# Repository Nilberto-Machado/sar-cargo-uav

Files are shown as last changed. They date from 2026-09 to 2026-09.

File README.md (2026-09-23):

# SAR Cargo UAV

## Overview

**SAR Cargo UAV** is an engineering project focused on the development of a long-range unmanned aerial vehicle for **Search and Rescue (SAR)**, emergency logistics, and transport of critical payloads to remote or difficult-to-access locations.

The project explores a **fixed-wing / hybrid VTOL UAV architecture** designed to combine efficient long-range cruise performance with the operational flexibility of vertical takeoff and landing.

The current design target is a UAV capable of transporting approximately **5 kg of useful payload** over missions of up to approximately **400 km**, with emphasis on endurance, manufacturability, aerodynamic efficiency, operational safety, and field deployment.

---

## Mission

The UAV is intended to support operations such as:

- Search and rescue missions
- Emergency medical supply delivery
- Transport of medicines, blood bags, and medical equipment
- Delivery of food, water, radios, batteries, and survival equipment
- Support to isolated communities
- Disaster response
- Logistics in areas affected by floods, landslides, fires, or infrastructure failure
- Long-range autonomous cargo missions
- Support to remote industrial and mining operations

---

## Main Design Targets

| Parameter | Target |
|---|---:|
| Payload | ~5 kg |
| Mission range | Up to ~400 km |
| Aircraft type | Fixed-wing / Hybrid VTOL UAV |
| Propulsion | Gasoline-based cruise propulsion under evaluation |
| Takeoff / landing | Conventional and/or VTOL architecture |
| Navigation | Autonomous / GPS-assisted |
| Mission type | Cargo, SAR and emergency logistics |
| Design approach | Modular and manufacturable |

These values represent current engineering targets and may evolve during aerodynamic, structural, propulsion, and operational studies.

---

## Aircraft Architecture

Several configurations are being evaluated as part of the project.

Current concepts include:

- Fixed-wing cargo UAV
- Hybrid VTOL
- Tilt-rotor configurations
- V-tail configurations
- Safe transition between hover and forward flight
- Modular propulsion arrangements
- Manufacturable fuselage concepts

The objective is to identify the best compromise between:

- range;
- payload;
- endurance;
- aerodynamic efficiency;
- structural mass;
- propulsion efficiency;
- VTOL capability;
- reliability;
- manufacturing complexity;
- maintenance;
- operational safety.

---

## Engineering Workflow

The project uses an iterative engineering workflow combining CAD, simulation, scripting, and design reviews.

```text
Mission Requirements
        │
        ▼
Conceptual Design
        │
        ▼
Aircraft Geometry
        │
        ▼
FreeCAD Parametric Model
        │
        ├──► Structural / Packaging Assessment
        │
        ├──► Propulsion Integration
        │
        └──► Transition / Collision Analysis
        │
        ▼
CFD Geometry Export
        │
        ▼
OpenFOAM
        │
        ▼
Aerodynamic Analysis
        │
        ▼
Design Optimization
        │
        ▼
Manufacturable Configuration
```

---

## CAD

The aircraft geometry is being developed primarily using **FreeCAD**.

The repository includes scripts and macros used to generate and evaluate multiple aircraft configurations.

Areas currently under development include:

- fuselage geometry;
- wing geometry;
- V-tail;
- propulsion mounting;
- cargo compartment;
- VTOL propulsion;
- tilt mechanisms;
- component clearance;
- aircraft packaging;
- manufacturability.

Python automation is used extensively to generate and evaluate alternative geometries.

---

## CFD

Aerodynamic simulation is performed using **OpenFOAM**.

The CFD workflow is intended to evaluate:

- external aerodynamic flow;
- pressure distribution;
- lift;
- drag;
- aerodynamic efficiency;
- wake structures;
- propulsion-airframe interaction;
- aerodynamic effects of VTOL components;
- stability-related characteristics.

Typical workflow:

```text
FreeCAD
   │
   ▼
Geometry Export
   │
   ▼
STL / CFD Geometry
   │
   ▼
OpenFOAM Mesh
   │
   ▼
Flow Simulation
   │
   ▼
Aerodynamic Results
```

---

## VTOL Development

Hybrid VTOL configurations are being investigated to enable operations where conventional runways are unavailable.

Engineering studies include:

- rotor placement;
- tilt mechanisms;
- transition between hover and cruise;
- mechanical interference;
- propeller clearance;
- center-of-gravity effects;
- propulsion redundancy;
- safe transition trajectories.

Several scripts in the repository are dedicated to collision detection and transition studies.

Examples include:

```text
check_tilt_collisions.py
check_mirrored_tilt_collisions.py
sweep_rear_tilt_pivot.py
```

---

## Manufacturability

A major objective of the project is to evolve from conceptual aircraft geometry toward a configuration that can realistically be manufactured.

Design considerations include:

- composite structures;
- aluminum components;
- modular construction;
- removable wings;
- propulsion accessibility;
- maintenance access;
- cargo loading;
- landing gear;
- component standardization;
- assembly sequence;
- field repairability.

---

## Repository Structure

The repository currently contains engineering tools, models, documentation, and simulation environments.

Example structure:

```text
sar-cargo-uav/
│
├── openfoam/
│   └── CFD simulation cases
│
├── Tech Spec/
│   └── Technical specifications
│
├── uav_cargo_freecad/
│   └── FreeCAD models
│
├── uav_cargo_vtol/
│   └── VTOL configurations
│
├── uav_cargo_refined/
│   └── Refined aircraft geometry
│
├── uav_cargo_manufacturable/
│   └── Manufacturable configuration
│
├── uav_cargo_animation/
│   └── Aircraft animations
│
├── uav_cargo_safe_transition/
│   └── VTOL transition studies
│
├── assess_fuselage_layout.py
├── build_uav_vtol_headless.py
├── check_tilt_collisions.py
├── check_mirrored_tilt_collisions.py
├── export_manufacturable_cfd.py
├── sweep_rear_tilt_pivot.py
│
└── README.md
```

The directory structure may change as the project evolves.

---

## Main Tools

The engineering workflow currently uses:

- **FreeCAD** — parametric aircraft modeling
- **Python** — geometry generation and engineering automation
- **OpenFOAM** — computational fluid dynamics
- **Git / GitHub** — version control
- **PowerShell** — development environment automation
- **ParaView** — CFD visualization

---

## Design Priorities

The development follows several key priorities.

### 1. Mission capability

The UAV must be capable of transporting a meaningful payload over long distances.

### 2. Aerodynamic efficiency

Long-range missions require high lift-to-drag efficiency and careful aerodynamic optimization.

### 3. Operational flexibility

VTOL capability may allow operations without conventional runways.

### 4. Reliability

Search-and-rescue aircraft must prioritize predictable and fault-tolerant behavior.

### 5. Manufacturability

The design should be capable of progressing from a CAD concept to an aircraft that can realistically be manufactured and maintained.

### 6. Modular architecture

Subsystems should be replaceable and configurable whenever practical.

---

## Future Development

Planned engineering activities include:

- aerodynamic optimization;
- wing sizing refinement;
- propulsion sizing;
- gasoline engine evaluation;
- propeller optimization;
- VTOL propulsion sizing;
- fuel consumption modeling;
- center-of-gravity analysis;
- stability analysis;
- structural analysis;
- landing gear design;
- cargo compartment refinement;
- flight-control architecture;
- autopilot integration;
- telemetry;
- communication systems;
- mission planning;
- redundancy analysis;
- fail-safe architecture;
- prototype manufacturing;
- ground testing;
- flight testing.

---

## Project Philosophy

SAR Cargo UAV is being developed as an engineering platform rather than only as a single aircraft model.

The long-term objective is to build a modular design and simulation environment capable of supporting multiple UAV configurations for emergency logistics and autonomous cargo transportation.

The project combines:

**CAD + CFD + automation + simulation + manufacturing engineering + autonomous flight systems**

into a unified development workflow.

---

## Project Status

**Current phase:** Concept development / preliminary engineering.

The aircraft geometry,

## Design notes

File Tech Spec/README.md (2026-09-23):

# Tech Spec — UAV híbrido VTOL cargueiro/de resgate

Pacote consolidado em 22/09/2026.

## Conteúdo

- `Tech_Spec_UAV_Hybrid_VTOL.docx`: documento mestre para revisão.
- `TECH_SPEC.md`: especificação técnica controlada em texto.
- `BOM_Compras.csv`: lista mestra de compras.
- `Data sheets/`: uma ficha técnica para cada uma das 71 linhas da BOM.

## Regra de maturidade

Nenhum item marcado **compra bloqueada**, **TBD crítico**, **TBD** ou **sob medida** está liberado para pedido. “Arquitetura aceita” significa que a função foi aceita, não que a integração esteja certificada.

## Próximos gates

1. Fechar orçamento de massa, MTOW e centro de gravidade.
2. Medir empuxo/corrente/temperatura do conjunto VTOL.
3. Medir empuxo e consumo do motor a gasolina com hélice pusher.
4. Dimensionar pivôs, atuadores, travas e sensores de indexação.
5. Fechar balanço de energia e pack 12S.
6. Executar análise estrutural e prova de carga.
7. Atualizar CFD com camadas de parede e efeitos propulsivos.

O arquivo FreeCAD de referência permanece em `../uav_cargo_manufacturable/CargoUAV_HybridVTOL_Manufacturable.FCStd`.

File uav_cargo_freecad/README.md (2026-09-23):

# UAV cargueiro paramétrico — FreeCAD / OpenFOAM

Modelo conceitual simplificado de uma aeronave cargueira não tripulada, de asa fixa,
para CFD externo. A geometria evita antenas, dobradiças, entradas de ar, parafusos e
outras escalas pequenas que encarecem o `snappyHexMesh` sem ajudar na análise global.

> Este é um modelo aerodinâmico conceitual, não um projeto estrutural, de estabilidade,
> propulsão ou certificação. As metas de 5 kg e 400 km são requisitos de missão ainda
> não demonstrados por este CAD.

## Arquivos

- `CargoUAV_CFD.FCStd` — documento nativo FreeCAD com parâmetros, sólido principal e
  disco atuador opcional.
- `build_uav.py` — fonte paramétrica; altere `PARAMS` e execute novamente para regenerar.
- `exports/CargoUAV_airframe.step` — aerofólio/fuselagem/empenagem unidos em um sólido.
- `exports/CargoUAV_with_propeller_disk.step` — sólido principal mais o disco opcional.
- `exports/CargoUAV_airframe.stl` — superfície triangulada principal para OpenFOAM.
- `exports/CargoUAV_propeller_disk.stl` — disco separado para modelo atuador/MRF.
- `validation_report.txt` — verificação de validade, fechamento, sólidos e dimensões.

## Dimensões principais

| Parâmetro | Valor |
|---|---:|
| Comprimento da fuselagem | 2,850 m |
| Envergadura | 4,200 m |
| Corda da asa, raiz / ponta | 0,620 / 0,340 m |
| Perfil da asa | NACA 0012 simétrico simplificado |
| Envergadura do estabilizador horizontal | 1,350 m |
| Altura da deriva | 0,620 m |
| Diâmetro do disco da hélice pusher | 0,900 m |
| Largura / altura máximas da fuselagem | 0,520 / 0,600 m |
| Meta de carga útil | 5 kg |
| Meta de alcance | 400 km |

Sistema de eixos: `+X` para a cauda, `+Y` para a asa direita e `+Z` para cima. O CAD e
os STEP/STL estão em milímetros.

## Parametrização e nova exportação

1. Edite somente o dicionário `PARAMS` no início de `build_uav.py`.
2. Execute no Prompt/PowerShell:

   ```powershell
   & "E:\Program Files\FreeCAD 1.1\bin\FreeCADCmd.exe" build_uav.py
   ```

3. Abra `CargoUAV_CFD.FCStd` para inspeção visual. O objeto `Parameters` registra os
   valores usados; a fonte de verdade para regeneração é `build_uav.py`.

No FreeCAD GUI, uma exportação manual equivalente é: selecione `Airframe`, use
**File > Export**, escolha STEP ou STL e mantenha milímetros. Para o STL fornecido, a
deflexão linear usada é 1,0 mm e a angular é 0,15 rad.

## Uso no OpenFOAM / snappyHexMesh

1. Copie `CargoUAV_airframe.stl` para `constant/triSurface/`.
2. Como o OpenFOAM normalmente trabalha em metros, aplique escala `0.001` ao importar
   (por exemplo, com `surfaceTransformPoints -scale '(0.001 0.001 0.001)'`). Confirme a
   sintaxe exata da sua versão do OpenFOAM.
3. Rode `surfaceCheck constant/triSurface/CargoUAV_airframe.stl`. O resultado esperado
   é uma superfície fechada, sem bordas abertas e com uma região principal.
4. No `snappyHexMeshDict`, use o STL como `triSurfaceMesh`, marque a superfície como
   `wall` e posicione `locationInMesh` no domínio externo, longe da aeronave.
5. Comece com 2–3 níveis de refinamento na aeronave, adicione caixas de refinamento na
   esteira e faça estudo de independência de malha. Refine bordo de ataque, bordo de
   fuga e ponta de asa conforme o objetivo aerodinâmico.
6. Para uma primeira simulação de célula limpa, ignore o arquivo do disco. Para empuxo
   simplificado, importe o disco separadamente e configure-o segundo o modelo atuador,
   `fvOptions` ou região rotativa compatível com sua versão do OpenFOAM.

O sólido principal foi unido por Boolean e salvo como um único corpo fechado. O disco
da hélice é deliberadamente separado porque não faz parte da parede estanque do avião.

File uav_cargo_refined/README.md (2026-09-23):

# UAV cargueiro híbrido VTOL - revisão aerodinâmica fundamentada

Esta pasta contém uma nova variante paramétrica. Ela preserva os modelos anteriores e
aplica critérios de projeto conceitual, aerodinâmica de asa e estabilidade extraídos das
referências técnicas fornecidas pelo usuário.

## Alterações principais

- asa de 4,20 m mantida, com área reduzida de 2,604 para 2,268 m²;
- alongamento aumentado de 6,77 para 7,78;
- taper alterado de 0,512 para 0,459, próximo ao valor recomendado para asa reta;
- perfil simétrico substituído por NACA 2415 na raiz, transicionando para NACA 2412;
- incidência de +2° na raiz e 0° na ponta, criando 2° de washout;
- cauda em V aumentada e inclinada a 38°, com volumes equivalentes aproximados
  `Vh = 0,50` e `Vv = 0,041`;
- CG preliminar consolidado em X=1,070 m, com envelope X=1,010-1,120 m;
- naceles de cruzeiro suavizadas e hélice pusher aumentada de 0,54 para 0,60 m;
- fuselagem preserva o volume central, mas recebe nariz e cone de cauda mais suaves.

## Arquivos gerados

- `CargoUAV_Refined_CFD.FCStd`: modelo nativo FreeCAD;
- `exports/CargoUAV_Refined_airframe.step`: sólido externo watertight;
- `exports/CargoUAV_Refined_airframe.stl`: superfície para `snappyHexMesh`;
- `exports/CargoUAV_Refined_with_pusher.step`: fuselagem e disco pusher separado;
- `exports/CargoUAV_Refined_complete.step`: airframe e cinco discos separados;
- `validation_report.json`: validade geométrica e métricas calculadas.

## Regeneração

```powershell
& "E:\Program Files\FreeCAD 1.1\bin\FreeCADCmd.exe" build_refined_uav.py
```

## Estado de maturidade

Este é um candidato conceitual, não um projeto liberado para fabricação. A alteração de
asa invalida a malha CFD anterior. Antes de congelar a geometria, são obrigatórios:

1. nova malha OpenFOAM com camadas prismáticas e estudo de independência;
2. polar incluindo transição/estol e avaliação de `y+`;
3. VLM ou CFD para ponto neutro, margem estática e autoridade dos ruddervators;
4. fechamento real de massa/CG em todas as condições de combustível e carga;
5. dimensionamento estrutural, aeroelasticidade, flutter e ensaios dos tilt-rotors.

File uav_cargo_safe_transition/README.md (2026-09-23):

# Transição segura dos motores basculantes

Esta macro substitui a sequência anterior, que inclinava os motores enquanto as hélices
ainda giravam. O novo intertravamento impede qualquer movimento de tilt enquanto a RPM
dos rotores elétricos for diferente de zero ou a trava das pás não estiver confirmada.

## Sequência

| Tempo | Operação | VTOL | Tilt | Pusher |
|---:|---|---:|---:|---:|
| 0–6 s | Spin-up e decolagem | até 1600 rpm | 0° | parada |
| 6–9 s | Partida da pusher | 1600 rpm | 0° | 0→5200 rpm |
| 9–11 s | Transferência de sustentação | 1600→0 rpm | 0° | 5200→6200 rpm |
| 11–12 s | Indexação transversal das pás | 0 rpm | 0° | 6200 rpm |
| 12–14 s | Basculamento após travamento | 0 rpm e travado | 0→−90° | 6200→6500 rpm |
| 14–20 s | Cruzeiro | parado e travado | −90° | 6500 rpm |

As pás são estacionadas a 90° no eixo local, ficando transversais ao boom antes do
basculamento. O estado pode ser acompanhado nas propriedades `RotorLock` e
`TiltPermission` de `AnimationState`.

Este intertravamento é apenas lógico/cinemático. Um mecanismo real também deve possuir
sensor de RPM zero, encoder de posição, pino de trava redundante, detecção de trava,
limites mecânicos e procedimento de retorno caso alguma unidade não confirme a posição.

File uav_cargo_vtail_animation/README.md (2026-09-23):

# Animação corrigida com cauda em V e motores basculantes

Esta revisão substitui a empenagem convencional por duas superfícies inclinadas a 40°
e adiciona basculamento aos quatro conjuntos elétricos.

Cada conjunto possui duas juntas independentes:

- `Joint_Tilt_*`: revolução em torno do eixo transversal local `+Y`, com curso de 0°
  na decolagem a −90° no cruzeiro.
- `Joint_Spin_*`: rotação da hélice em torno de `+Z` local ao pod. Como é filha do
  conjunto basculante, a direção desse eixo acompanha a inclinação do motor.

| Motor | Pivô de basculamento em mm | Eixo de tilt | Centro do rotor relativo ao pivô |
|---|---:|---:|---:|
| FL | `(600, -950, 53,4)` | `(0, 1, 0)` | `(0, 0, 167)` |
| FR | `(600, 950, 53,4)` | `(0, 1, 0)` | `(0, 0, 167)` |
| RL | `(1850, -950, 53,4)` | `(0, 1, 0)` | `(0, 0, 167)` |
| RR | `(1850, 950, 53,4)` | `(0, 1, 0)` | `(0, 0, 167)` |

Durante a transição, a hélice traseira acelera de 0 a 6000 rpm enquanto os pods passam
de 0° para −90° e os rotores elétricos reduzem de 1600 rpm até parar. No cruzeiro, os
discos elétricos ficam alinhados com o escoamento para reduzir a área frontal.

Para executar, abra `CargoUAV_HybridVTOL_VTail_TiltRotor_Animated.FCStd` e rode
`RunVTailTiltRotorAnimation.FCMacro` em **Macro > Macros**. Use a macro `Stop...` para
parar e retornar à posição inicial.

Esta é uma verificação cinemática. O mecanismo real ainda necessita dimensionamento de
atuador, rolamentos, trava mecânica, velocidade de basculamento e análise de cargas.

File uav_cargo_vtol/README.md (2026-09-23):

# UAV cargueiro híbrido VTOL — FreeCAD e OpenFOAM

Revisão do modelo conceitual para a configuração consolidada: quatro motores elétricos
de sustentação vertical, motor traseiro a gasolina para cruzeiro e starter-generator.
O corpo principal continua simplificado e adequado a CFD externo.

## Configuração representada

| Parâmetro | Valor |
|---|---:|
| Envergadura | 4,20 m |
| Comprimento | 2,85 m |
| Área alar geométrica | 2,604 m² |
| Alongamento | 6,77 |
| Corda da asa, raiz / ponta | 0,82 / 0,42 m |
| Rotores VTOL | 4 × 0,76 m |
| Hélice pusher representada | 0,54 m |
| Carga útil alvo | 5 kg |
| MTOW preliminar | 21 kg |
| Bateria VTOL de referência | 12S, 800 Wh |
| Starter-generator de referência | 750 W |
| Tanque preliminar | 4 L |
| Alcance pretendido | 400 km |

O MTOW, potência dos motores, bateria e combustível ainda são parâmetros preliminares.
O CAD não demonstra desempenho, autonomia, resistência estrutural ou segurança de voo.

## Arquivos

- `CargoUAV_HybridVTOL_CFD.FCStd`: documento nativo FreeCAD.
- `build_uav_vtol.py`: fonte paramétrica e regenerável.
- `exports/CargoUAV_HybridVTOL_airframe.step`: sólido externo limpo, sem discos.
- `exports/CargoUAV_HybridVTOL_airframe.stl`: parede externa para `snappyHexMesh`.
- `exports/CargoUAV_HybridVTOL_complete.step`: airframe e cinco discos separados.
- `exports/CargoUAV_HybridVTOL_pusher_disk.stl`: disco do motor a gasolina.
- `exports/CargoUAV_HybridVTOL_vtol_disks.stl`: quatro discos elétricos.
- `validation_report.txt`: validade, fechamento, número de sólidos e dimensões.

O documento FreeCAD também contém envelopes internos ocultos para carga útil, bateria
VTOL, tanque de combustível e starter-generator. Esses objetos não são exportados para
os arquivos de CFD.

## Regeneração

Edite `P` no início de `build_uav_vtol.py` e execute:

```powershell
& "E:\Program Files\FreeCAD 1.1\bin\FreeCADCmd.exe" build_uav_vtol.py
```

Para conferir todos os arquivos depois da geração:

```powershell
& "E:\Program Files\FreeCAD 1.1\bin\FreeCADCmd.exe" validate_delivery.py
```

## Uso no OpenFOAM

Copie `CargoUAV_HybridVTOL_airframe.stl` para `constant/triSurface/`. Os arquivos estão
em milímetros; converta para metros com escala `0.001`. Execute `surfaceCheck` antes do
`snappyHexMesh`. Para CFD de cruzeiro limpo, use apenas o airframe. Importe os discos
separadamente somente em casos com modelo atuador ou região rotativa.

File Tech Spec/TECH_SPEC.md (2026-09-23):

# Especificação técnica consolidada

## Configuração
- **Tipo:** UAV cargueiro/de resgate híbrido VTOL de asa fixa
- **Status:** Configuração conceitual consolidada; não liberada para fabricação ou compra integral
- **Envergadura:** 4,20 m
- **Comprimento:** 2,85 m (envelope atual; requisito inicial 2,6–3,0 m)
- **Área alar:** 2,604 m²
- **Corda raiz / ponta:** 0,820 m / 0,420 m
- **Afilamento:** 0,512
- **Corda aerodinâmica média:** 0,6415 m
- **Alongamento geométrico:** AR ≈ 6,77
- **Empenagem:** Cauda em V, ângulo consolidado de 40°
- **Carga útil:** Até 5 kg — meta
- **Alcance:** 400 km — meta a validar por ensaio de consumo e reserva
- **Velocidade CFD de referência:** 25 m/s, α = 0°
- **Centro de gravidade alvo:** x ≈ 1,05–1,085 m; referência de momentos x = 1,07 m
- **Propulsão VTOL:** 4 motores elétricos 12S em naceles inclináveis
- **Pivôs dianteiros:** x = 0,600 m; inclinação de cruzeiro para frente: −90°
- **Pivôs traseiros:** x = 2,000 m; inclinação de cruzeiro para trás: +90°
- **Propulsão de cruzeiro:** Motor traseiro a gasolina em configuração pusher
- **Geração elétrica:** Starter-generator dedicado; motores VTOL não são assumidos como geradores nesta revisão
- **MTOW:** TBD — gate obrigatório antes da compra de motores, ESCs, pack, tilt, estrutura e paraquedas

## Conceito operacional

A aeronave decola e pousa verticalmente com quatro rotores elétricos. Após atingir altura e condições seguras, o motor traseiro a gasolina é acionado pelo sistema starter-generator e assume o cruzeiro. O starter-generator pode alimentar o barramento e recarregar a bateria dentro dos limites do pack. Os motores VTOL não são considerados geradores nesta revisão, evitando arrasto, controle complexo e riscos de overspeed.

## Intertravamento obrigatório dos tilt-rotors

A nacele só pode iniciar o movimento quando, para aquele rotor, houver confirmação independente de: comando de torque zero; RPM abaixo do limite; hélice na janela angular indexada; trava da posição atual liberada; trajetória livre; e alimentação do atuador válida. Ao chegar à nova posição, a trava mecânica deve engatar e dois sinais coerentes devem confirmar posição/trava antes de liberar potência ao motor.

Sequência de falha: qualquer discordância congela a transição, mantém ou retorna à última posição mecanicamente segura e impede reenergização do rotor afetado. Os rotores dianteiros giram para frente; os traseiros giram para trás. É proibido girar naceles com hélices em rotação livre significativa.

## Estado da validação CFD

Caso base OpenFOAM 14, 25 m/s e α=0°, malha de 269.773 células. Resultado preliminar médio entre passos 140–150: Cd≈0,06546, Cl≈−0,01247 e Cm≈0,01091. A malha ainda não possui camadas de parede nem representação das hélices; os coeficientes não liberam o projeto.

## Gates de liberação de compras

- G1 Massa/CG: MTOW, centros de massa e envelopes fechados.
- G2 VTOL: razão empuxo/peso ≥1,5 e margens elétricas/térmicas medidas.
- G3 Cruzeiro: potência, consumo, alcance de 400 km e reserva demonstrados.
- G4 Tilt: cargas, folgas, indexação, travas e análise de falha aprovadas.
- G5 Energia: pack, proteção, redundância e starter-generator validados.
- G6 Estrutura: cargas limite/última, FEA e provas estáticas concluídas.
- G7 Segurança/operação: paraquedas, failsafes, regulamentação e plano de ensaios aprovados.

## Rastreabilidade e ressalvas

As dimensões acima vêm do modelo paramétrico atual. Cálculos antigos do documento Arduino (como asa de 3 m e massas de 10/19 kg) são históricos e foram superados quando conflitantes. Modelos comerciais listados são candidatos técnicos, não autorização de compra. Confirme revisão, disponibilidade, homologação e ficha oficial diretamente com o fabricante no momento da aquisição.

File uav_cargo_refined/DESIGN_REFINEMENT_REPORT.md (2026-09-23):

# Relatório de refinamento aerodinâmico

## Base de decisão

A revisão usa os princípios convergentes das referências fornecidas: arrasto induzido
decresce com o alongamento; taper próximo de 0,4-0,5 é apropriado para asas retas;
washout favorece estol iniciando na raiz; Reynolds e rugosidade devem ser compatíveis
com os dados de perfil; e a cauda deve ser dimensionada por volume e verificada por
margem estática e dinâmica.

## Comparação geométrica

| Parâmetro | Modelo anterior | Revisão |
|---|---:|---:|
| Envergadura | 4,20 m | 4,20 m |
| Área alar | 2,604 m² | 2,268 m² |
| Alongamento | 6,77 | 7,78 |
| Taper | 0,512 | 0,459 |
| Perfil | NACA 00xx simétrico | NACA 2415 -> 2412 |
| Twist geométrico | 0° | 2° de washout |
| Área verdadeira da cauda em V | 0,640 m² | 0,770 m² |
| Ângulo da cauda em V | 40° | 38° |
| Volume horizontal equivalente | ~0,29 | ~0,50 |
| Volume vertical equivalente | ~0,031 | ~0,041 |
| Referência de CG | conflitante: 1,07/1,35 m | alvo 1,070 m |

## Desempenho preliminar calculado

Com MTOW ainda preliminar de 21 kg e velocidade de cruzeiro de 21 m/s:

- carga alar: aproximadamente 90,8 N/m² (9,26 kg/m²);
- `Cl` de cruzeiro requerido: aproximadamente 0,337;
- velocidade de estol estimada: 10,7 m/s para `Clmax=1,3`;
- Reynolds de cruzeiro: aproximadamente 1,04 milhão na raiz e 0,48 milhão na ponta;
- área total dos quatro discos VTOL: aproximadamente 1,815 m².

Esses números são verificações de coerência, não garantias de desempenho.

## Relação com o CFD existente

A polar anterior mostrou crescimento de sustentação até +12°, aumento rápido de
arrasto acima de +8° e momento de arfagem progressivamente negativo. Ela continua útil
como referência do desenho anterior, mas não pode ser transferida para a nova asa. O
perfil cambrado, o washout, a área menor e a cauda maior exigem remalhamento completo.

## Gates antes de fabricação

- pesar todos os componentes e fechar MTOW/CG, incluindo combustível consumido;
- demonstrar margem estática positiva no envelope inteiro, com meta inicial de 10-18%;
- verificar controle em pitch/yaw e acoplamento adverso da cauda em V em 6-DOF;
- verificar que o estol começa na raiz e preserva autoridade dos ailerons;
- validar potência, hélices e transição VTOL em bancada e em testes progressivos;
- executar análise estrutural, cargas de rajada, fadiga e flutter.

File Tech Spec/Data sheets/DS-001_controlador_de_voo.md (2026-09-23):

# DS-001 — Controlador de voo

## Identificação

| Campo | Valor |
|---|---|
| Categoria | Aviónica |
| Quantidade | 1 |
| Maturidade | Arquitetura aceita |
| Candidato/modelo | Holybro Pixhawk 6X |
| Liberação de compra | Revisão de integração obrigatória antes do pedido |

## Função

Controle de voo, navegação, failsafes e registro primário.

## Requisitos mínimos de compra

Autopiloto classe H7, IMUs redundantes, barômetros redundantes, CAN, Ethernet e entradas de alimentação redundantes.

## Interfaces

MAVLink/CAN/UART; 5 V regulados; servo rail isolado.

## Critérios de aceitação

Teste de alimentação A/B, sensores, logging, watchdog, RTL e perda de enlace.

## Dependências antes da seleção

Firmware ArduPilot/PX4 e integração do sistema de energia.

## Data sheet de referência

https://docs.holybro.com/autopilot/pixhawk-6x/technical-specification

## Documentos que o fornecedor deve entregar

- Data sheet com revisão e part number exatos.
- Desenho dimensional e interfaces.
- Limites elétricos, térmicos, mecânicos e ambientais aplicáveis.
- Curvas de desempenho relevantes e condições do ensaio.
- Certificado de material/conformidade quando aplicável.
- Instruções de instalação, inspeção e vida útil/manutenção.

## Registro de recebimento

- Fabricante / fornecedor: ____________________
- Part number / revisão: ____________________
- Lote / número de série: ____________________
- Data de recebimento: ____________________
- Inspeção de recebimento: APROVADO / REPROVADO
- Responsável: ____________________

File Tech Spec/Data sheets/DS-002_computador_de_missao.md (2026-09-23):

# DS-002 — Computador de missão

## Identificação

| Campo | Valor |
|---|---|
| Categoria | Aviónica |
| Quantidade | 1 |
| Maturidade | Arquitetura aceita |
| Candidato/modelo | Raspberry Pi 5 — 8 GB |
| Liberação de compra | Revisão de integração obrigatória antes do pedido |

## Função

Visão computacional, comunicações de alto nível e processamento de missão.

## Requisitos mínimos de compra

BCM2712, 8 GB, alimentação 5 V/5 A, refrigeração ativa e desligamento controlado.

## Interfaces

Ethernet/USB/UART com Pixhawk; câmera CSI; armazenamento local.

## Critérios de aceitação

Burn-in de 4 h, carga de CPU, perda/retorno de energia e temperatura no compartimento.

## Dependências antes da seleção

Conversores DC/DC redundantes e solução térmica.

## Data sheet de referência

https://datasheets.raspberrypi.com/rpi5/raspberry-pi-5-product-brief.pdf

## Documentos que o fornecedor deve entregar

- Data sheet com revisão e part number exatos.
- Desenho dimensional e interfaces.
- Limites elétricos, térmicos, mecânicos e ambientais aplicáveis.
- Curvas de desempenho relevantes e condições do ensaio.
- Certificado de material/conformidade quando aplicável.
- Instruções de instalação, inspeção e vida útil/manutenção.

## Registro de recebimento

- Fabricante / fornecedor: ____________________
- Part number / revisão: ____________________
- Lote / número de série: ____________________
- Data de recebimento: ____________________
- Inspeção de recebimento: APROVADO / REPROVADO
- Responsável: ____________________

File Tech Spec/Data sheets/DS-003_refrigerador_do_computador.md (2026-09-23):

# DS-003 — Refrigerador do computador

## Identificação

| Campo | Valor |
|---|---|
| Categoria | Aviónica |
| Quantidade | 1 |
| Maturidade | Candidato |
| Candidato/modelo | Raspberry Pi Active Cooler |
| Liberação de compra | BLOQUEADA até fechamento dos gates aplicáveis |

## Função

Manter o computador de missão abaixo do limite térmico.

## Requisitos mínimos de compra

Compatível com Raspberry Pi 5; operação contínua na temperatura interna prevista.

## Interfaces

Conector de fan do Raspberry Pi 5; fluxo de ar desobstruído.

## Critérios de aceitação

Teste térmico em solo com CPU a 100% e fuselagem fechada.

## Dependências antes da seleção

Projeto de dutos/ventilação.

## Data sheet de referência

https://www.raspberrypi.com/products/active-cooler/

## Documentos que o fornecedor deve entregar

- Data sheet com revisão e part number exatos.
- Desenho dimensional e interfaces.
- Limites elétricos, térmicos, mecânicos e ambientais aplicáveis.
- Curvas de desempenho relevantes e condições do ensaio.
- Certificado de material/conformidade quando aplicável.
- Instruções de instalação, inspeção e vida útil/manutenção.

## Registro de recebimento

- Fabricante / fornecedor: ____________________
- Part number / revisão: ____________________
- Lote / número de série: ____________________
- Data de recebimento: ____________________
- Inspeção de recebimento: APROVADO / REPROVADO
- Responsável: ____________________

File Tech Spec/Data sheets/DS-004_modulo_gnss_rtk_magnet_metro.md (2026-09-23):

# DS-004 — Módulo GNSS/RTK + magnetômetro

## Identificação

| Campo | Valor |
|---|---|
| Categoria | Aviónica |
| Quantidade | 1 |
| Maturidade | Candidato |
| Candidato/modelo | Holybro H-RTK NEO-F9P + RM3100 |
| Liberação de compra | BLOQUEADA até fechamento dos gates aplicáveis |

## Função

Posição, velocidade, rumo e possibilidade de RTK.

## Requisitos mínimos de compra

Dupla banda GNSS, RTK, magnetômetro RM3100; 4,75–5,25 V; massa aproximada 39 g.

## Interfaces

CAN/UART conforme variante; montagem afastada de potência e ignição.

## Critérios de aceitação

Aquisição a céu aberto, comparação de rumo, interferência com motor a gasolina ligado.

## Dependências antes da seleção

Mastro e plano de aterramento eletromagnético.

## Data sheet de referência

https://docs.holybro.com/gps-and-rtk-system/h-rtk-neo-f9p-series-rm3100-compass/specification

## Documentos que o fornecedor deve entregar

- Data sheet com revisão e part number exatos.
- Desenho dimensional e interfaces.
- Limites elétricos, térmicos, mecânicos e ambientais aplicáveis.
- Curvas de desempenho relevantes e condições do ensaio.
- Certificado de material/conformidade quando aplicável.
- Instruções de instalação, inspeção e vida útil/manutenção.

## Registro de recebimento

- Fabricante / fornecedor: ____________________
- Part number / revisão: ____________________
- Lote / número de série: ____________________
- Data de recebimento: ____________________
- Inspeção de recebimento: APROVADO / REPROVADO
- Responsável: ____________________

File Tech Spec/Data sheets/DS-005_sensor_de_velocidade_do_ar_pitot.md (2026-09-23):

# DS-005 — Sensor de velocidade do ar + pitot

## Identificação

| Campo | Valor |
|---|---|
| Categoria | Aviónica |
| Quantidade | 1 |
| Maturidade | Candidato |
| Candidato/modelo | Holybro MS5525 |
| Liberação de compra | BLOQUEADA até fechamento dos gates aplicáveis |

## Função

Medição de velocidade indicada e proteção do envelope.

## Requisitos mínimos de compra

Sensor diferencial digital, faixa adequada ao voo de 15–40 m/s, tubos resistentes a combustível/calor.

## Interfaces

I²C/CAN via interface; tomadas de pressão total/estática.

## Critérios de aceitação

Calibração zero, teste de vazamento, comparação em túnel/veículo.

## Dependências antes da seleção

Posição do pitot fora da esteira das hélices.

## Data sheet de referência

https://docs.holybro.com/peripherals/ms4525do-and-ms5525dso-i2c-airspeed-sensor

## Documentos que o fornecedor deve entregar

- Data sheet com revisão e part number exatos.
- Desenho dimensional e interfaces.
- Limites elétricos, térmicos, mecânicos e ambientais aplicáveis.
- Curvas de desempenho relevantes e condições do ensaio.
- Certificado de material/conformidade quando aplicável.
- Instruções de instalação, inspeção e vida útil/manutenção.

## Registro de recebimento

- Fabricante / fornecedor: ____________________
- Part number / revisão: ____________________
- Lote / número de série: ____________________
- Data de recebimento: ____________________
- Inspeção de recebimento: APROVADO / REPROVADO
- Responsável: ____________________

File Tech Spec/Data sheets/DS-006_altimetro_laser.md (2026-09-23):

# DS-006 — Altímetro laser

## Identificação

| Campo | Valor |
|---|---|
| Categoria | Aviónica |
| Quantidade | 1 |
| Maturidade | Candidato |
| Candidato/modelo | LightWare SF11/C |
| Liberação de compra | BLOQUEADA até fechamento dos gates aplicáveis |

## Função

Altura precisa na decolagem e no pouso VTOL.

## Requisitos mínimos de compra

Faixa 0,2–100 m, 20 Hz, precisão aproximada ±0,1 m, 5 V, massa aproximada 35 g.

## Interfaces

Serial/I²C; campo de visão desobstruído para baixo.

## Critérios de aceitação

Teste em superfícies clara/escura, poeira e inclinação; comparação com referência.

## Dependências antes da seleção

Janela óptica e suporte antivibração.

## Data sheet de referência

https://lightwarelidar.com/wp-content/uploads/2025/07/SF11-Laser-Altimeter-Manual-Rev-10.pdf

## Documentos que o fornecedor deve entregar

- Data sheet com revisão e part number exatos.
- Desenho dimensional e interfaces.
- Limites elétricos, térmicos, mecânicos e ambientais aplicáveis.
- Curvas de desempenho relevantes e condições do ensaio.
- Certificado de material/conformidade quando aplicável.
- Instruções de instalação, inspeção e vida útil/manutenção.

## Registro de recebimento

- Fabricante / fornecedor: ____________________
- Part number / revisão: ____________________
- Lote / número de série: ____________________
- Data de recebimento: ____________________
- Inspeção de recebimento: APROVADO / REPROVADO
- Responsável: ____________________

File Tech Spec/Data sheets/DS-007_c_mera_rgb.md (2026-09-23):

# DS-007 — Câmera RGB

## Identificação

| Campo | Valor |
|---|---|
| Categoria | Missão |
| Quantidade | 1 |
| Maturidade | Candidato |
| Candidato/modelo | Raspberry Pi Camera Module 3 Wide |
| Liberação de compra | BLOQUEADA até fechamento dos gates aplicáveis |

## Função

Busca visual, registro e apoio à navegação.

## Requisitos mínimos de compra

Sony IMX708, 12 MP, autofoco, variante wide; proteção óptica substituível.

## Interfaces

CSI para Raspberry Pi 5.

## Critérios de aceitação

Foco, exposição, vibração, rolling shutter e gravação sustentada.

## Dependências antes da seleção

Cabo CSI com comprimento final e janela frontal.

## Data sheet de referência

https://datasheets.raspberrypi.com/camera/camera-module-3-product-brief.pdf

## Documentos que o fornecedor deve entregar

- Data sheet com revisão e part number exatos.
- Desenho dimensional e interfaces.
- Limites elétricos, térmicos, mecânicos e ambientais aplicáveis.
- Curvas de desempenho relevantes e condições do ensaio.
- Certificado de material/conformidade quando aplicável.
- Instruções de instalação, inspeção e vida útil/manutenção.

## Registro de recebimento

- Fabricante / fornecedor: ____________________
- Part number / revisão: ____________________
- Lote / número de série: ____________________
- Data de recebimento: ____________________
- Inspeção de recebimento: APROVADO / REPROVADO
- Responsável: ____________________

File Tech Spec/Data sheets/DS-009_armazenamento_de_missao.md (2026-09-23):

# DS-009 — Armazenamento de missão

## Identificação

| Campo | Valor |
|---|---|
| Categoria | Aviónica |
| Quantidade | 2 |
| Maturidade | TBD |
| Candidato/modelo | microSD High Endurance ou NVMe industrial |
| Liberação de compra | BLOQUEADA até fechamento dos gates aplicáveis |

## Função

Sistema operacional e logs redundantes.

## Requisitos mínimos de compra

Alta resistência de escrita, temperatura industrial preferencial, capacidade ≥128 GB.

## Interfaces

microSD ou M.2 HAT; imagem de recuperação documentada.

## Critérios de aceitação

Teste SMART/velocidade, 8 h de escrita e recuperação após corte de energia.

## Dependências antes da seleção

Escolha final do gabinete do Raspberry Pi.

## Data sheet de referência

Ficha do fornecedor a exigir antes da compra.

## Documentos que o fornecedor deve entregar

- Data sheet com revisão e part number exatos.
- Desenho dimensional e interfaces.
- Limites elétricos, térmicos, mecânicos e ambientais aplicáveis.
- Curvas de desempenho relevantes e condições do ensaio.
- Certificado de material/conformidade quando aplicável.
- Instruções de instalação, inspeção e vida útil/manutenção.

## Registro de recebimento

- Fabricante / fornecedor: ____________________
- Part number / revisão: ____________________
- Lote / número de série: ____________________
- Data de recebimento: ____________________
- Inspeção de recebimento: APROVADO / REPROVADO
- Responsável: ____________________

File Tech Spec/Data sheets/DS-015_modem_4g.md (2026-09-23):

# DS-015 — Modem 4G

## Identificação

| Campo | Valor |
|---|---|
| Categoria | Comunicação |
| Quantidade | 1 |
| Maturidade | Candidato |
| Candidato/modelo | Waveshare SIM7600G-H 4G HAT |
| Liberação de compra | BLOQUEADA até fechamento dos gates aplicáveis |

## Função

Canal secundário de dados e supervisão quando houver cobertura.

## Requisitos mínimos de compra

LTE Cat-4 global; confirmar bandas da operadora brasileira; GNSS do modem não substitui GNSS de voo.

## Interfaces

USB para Raspberry Pi; alimentação 5 V com picos suportados.

## Critérios de aceitação

Teste de bandas, handover, consumo de pico e perda de rede.

## Dependências antes da seleção

SIM/plano de dados e cobertura operacional.

## Data sheet de referência

https://www.waveshare.com/SIM7600G-H-4G-HAT.htm

## Documentos que o fornecedor deve entregar

- Data sheet com revisão e part number exatos.
- Desenho dimensional e interfaces.
- Limites elétricos, térmicos, mecânicos e ambientais aplicáveis.
- Curvas de desempenho relevantes e condições do ensaio.
- Certificado de material/conformidade quando aplicável.
- Instruções de instalação, inspeção e vida útil/manutenção.

## Registro de recebimento

- Fabricante / fornecedor: ____________________
- Part number / revisão: ____________________
- Lote / número de série: ____________________
- Data de recebimento: ____________________
- Inspeção de recebimento: APROVADO / REPROVADO
- Responsável: ____________________

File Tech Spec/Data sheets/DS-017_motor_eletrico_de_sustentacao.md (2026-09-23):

# DS-017 — Motor elétrico de sustentação

## Identificação

| Campo | Valor |
|---|---|
| Categoria | Propulsão VTOL |
| Quantidade | 4 |
| Maturidade | Candidato — compra bloqueada |
| Candidato/modelo | T-Motor U10 II KV100 |
| Liberação de compra | BLOQUEADA até fechamento dos gates aplicáveis |

## Função

Sustentação VTOL e, quando comandado, contribuição elétrica na transição.

## Requisitos mínimos de compra

12S; massa aproximada 415 g; compatível com hélice 30×10,5; margem térmica e empuxo final validados em bancada.

## Interfaces

ESC trifásico; flange estrutural; sensor de rotação recomendado.

## Critérios de aceitação

Curva empuxo/corrente, temperatura, vibração, balanceamento e falha de um motor.

## Dependências antes da seleção

MTOW fechado e razão empuxo/peso VTOL ≥1,5.

## Data sheet de referência

https://store.tmotor.com/product/u10-2-u-efficiency.html

## Documentos que o fornecedor deve entregar

- Data sheet com revisão e part number exatos.
- Desenho dimensional e interfaces.
- Limites elétricos, térmicos, mecânicos e ambientais aplicáveis.
- Curvas de desempenho relevantes e condições do ensaio.
- Certificado de material/conformidade quando aplicável.
- Instruções de instalação, inspeção e vida útil/manutenção.

## Registro de recebimento

- Fabricante / fornecedor: ____________________
- Part number / revisão: ____________________
- Lote / número de série: ____________________
- Data de recebimento: ____________________
- Inspeção de recebimento: APROVADO / REPROVADO
- Responsável: ____________________

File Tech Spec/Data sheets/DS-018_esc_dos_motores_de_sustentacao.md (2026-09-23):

# DS-018 — ESC dos motores de sustentação

## Identificação

| Campo | Valor |
|---|---|
| Categoria | Propulsão VTOL |
| Quantidade | 4 |
| Maturidade | Candidato — compra bloqueada |
| Candidato/modelo | T-Motor ALPHA 80A 12S |
| Liberação de compra | BLOQUEADA até fechamento dos gates aplicáveis |

## Função

Comutação e controle dos quatro motores VTOL.

## Requisitos mínimos de compra

12S, corrente contínua e refrigeração compatíveis com curva real; telemetria desejável.

## Interfaces

Bateria 12S, motor U10 II, PWM/DShot conforme integração.

## Critérios de aceitação

Bancada em potência máxima, rampa, corte, perda de sinal e temperatura.

## Dependências antes da seleção

Curva final de hélice/motor e projeto de ventilação.

## Data sheet de referência

https://store.tmotor.com/product/alpha-80a-12s-esc.html

## Documentos que o fornecedor deve entregar

- Data sheet com revisão e part number exatos.
- Desenho dimensional e interfaces.
- Limites elétricos, térmicos, mecânicos e ambientais aplicáveis.
- Curvas de desempenho relevantes e condições do ensaio.
- Certificado de material/conformidade quando aplicável.
- Instruções de instalação, inspeção e vida útil/manutenção.

## Registro de recebimento

- Fabricante / fornecedor: ____________________
- Part number / revisão: ____________________
- Lote / número de série: ____________________
- Data de recebimento: ____________________
- Inspeção de recebimento: APROVADO / REPROVADO
- Responsável: ____________________

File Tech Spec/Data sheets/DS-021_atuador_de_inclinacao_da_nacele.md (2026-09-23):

# DS-021 — Atuador de inclinação da nacele

## Identificação

| Campo | Valor |
|---|---|
| Categoria | Tilt-rotor |
| Quantidade | 4 |
| Maturidade | TBD crítico |
| Candidato/modelo | Atuador eletromecânico industrial com feedback absoluto |
| Liberação de compra | BLOQUEADA até fechamento dos gates aplicáveis |

## Função

Girar motores dianteiros para frente e traseiros para trás somente com hélices seguras.

## Requisitos mínimos de compra

Torque com fator ≥2 sobre pior carga aerodinâmica/inercial; feedback absoluto; retenção sem energia; baixa folga.

## Interfaces

Alimentação dedicada; CAN/PWM; eixo e mancais da nacele.

## Critérios de aceitação

Ciclagem ≥10.000, torque, folga, vibração, falha de energia e posição.

## Dependências antes da seleção

Cargas de transição e projeto mecânico dos pivôs.

## Data sheet de referência

Ficha do fornecedor a exigir antes da compra.

## Documentos que o fornecedor deve entregar

- Data sheet com revisão e part number exatos.
- Desenho dimensional e interfaces.
- Limites elétricos, térmicos, mecânicos e ambientais aplicáveis.
- Curvas de desempenho relevantes e condições do ensaio.
- Certificado de material/conformidade quando aplicável.
- Instruções de instalação, inspeção e vida útil/manutenção.

## Registro de recebimento

- Fabricante / fornecedor: ____________________
- Part number / revisão: ____________________
- Lote / número de série: ____________________
- Data de recebimento: ____________________
- Inspeção de recebimento: APROVADO / REPROVADO
- Responsável: ____________________

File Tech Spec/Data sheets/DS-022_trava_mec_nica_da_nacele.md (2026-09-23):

# DS-022 — Trava mecânica da nacele

## Identificação

| Campo | Valor |
|---|---|
| Categoria | Tilt-rotor |
| Quantidade | 4 |
| Maturidade | TBD crítico |
| Candidato/modelo | Pino/trava fail-safe com sensor duplo |
| Liberação de compra | BLOQUEADA até fechamento dos gates aplicáveis |

## Função

Imobilizar cada nacele em VTOL e cruzeiro sem depender do torque do atuador.

## Requisitos mínimos de compra

Fail-safe, confirmação independente de engate, resistência com fator estrutural definido.

## Interfaces

Interlock do controlador; batentes estruturais.

## Critérios de aceitação

Carga limite/última, engate contaminado, falha simples de sensor e 10.000 ciclos.

## Dependências antes da seleção

Geometria do pivô e cargas finais.

## Data sheet de referência

Ficha do fornecedor a exigir antes da compra.

## Documentos que o fornecedor deve entregar

- Data sheet com revisão e part number exatos.
- Desenho dimensional e interfaces.
- Limites elétricos, térmicos, mecânicos e ambientais aplicáveis.
- Curvas de desempenho relevantes e condições do ensaio.
- Certificado de material/conformidade quando aplicável.
- Instruções de instalação, inspeção e vida útil/manutenção.

## Registro de recebimento

- Fabricante / fornecedor: ____________________
- Part number / revisão: ____________________
- Lote / número de série: ____________________
- Data de recebimento: ____________________
- Inspeção de recebimento: APROVADO / REPROVADO
- Responsável: ____________________

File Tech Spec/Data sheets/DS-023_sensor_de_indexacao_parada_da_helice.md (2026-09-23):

# DS-023 — Sensor de indexação/parada da hélice

## Identificação

| Campo | Valor |
|---|---|
| Categoria | Tilt-rotor |
| Quantidade | 4 |
| Maturidade | TBD crítico |
| Candidato/modelo | Encoder/Hall redundante |
| Liberação de compra | BLOQUEADA até fechamento dos gates aplicáveis |

## Função

Confirmar RPM zero e posição angular segura antes do movimento da nacele.

## Requisitos mínimos de compra

Detecção redundante de velocidade zero e ângulo; imunidade EMI; resolução suficiente para folga estrutural.

## Interfaces

Motor/ESC e controlador de intertravamento.

## Critérios de aceitação

Falha de sensor, falso zero, parada fora da janela e vibração.

## Dependências antes da seleção

Definir posição segura de cada pá no CAD.

## Data sheet de referência

Ficha do fornecedor a exigir antes da compra.

## Documentos que o fornecedor deve entregar

- Data sheet com revisão e part number exatos.
- Desenho dimensional e interfaces.
- Limites elétricos, térmicos, mecânicos e ambientais aplicáveis.
- Curvas de desempenho relevantes e condições do ensaio.
- Certificado de material/conformidade quando aplicável.
- Instruções de instalação, inspeção e vida útil/manutenção.

## Registro de recebimento

- Fabricante / fornecedor: ____________________
- Part number / revisão: ____________________
- Lote / número de série: ____________________
- Data de recebimento: ____________________
- Inspeção de recebimento: APROVADO / REPROVADO
- Responsável: ____________________

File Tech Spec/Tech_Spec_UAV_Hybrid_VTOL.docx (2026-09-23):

# TECH SPEC UAV HÍBRIDO VTOL

Aeronave cargueira e de resgate — especificação e lista mestra de compras

Revisão | A — configuração conceitual consolidada
Data | 22/09/2026
Escopo | Tech Spec + BOM + fichas técnicas individuais
Status | NÃO LIBERADO PARA FABRICAÇÃO OU COMPRA INTEGRAL

Documento de engenharia preliminar. Modelos comerciais citados são candidatos e exigem fechamento dos gates técnicos.

# 1. Finalidade e controle de maturidade

Este documento consolida a configuração atual da aeronave, transforma a arquitetura em requisitos de compra verificáveis e fornece uma ficha técnica individual para cada linha da BOM. A prioridade é impedir compras prematuras de componentes que dependem de MTOW, cargas, energia ou ensaios ainda abertos.

- Arquitetura aceita: Função e arquitetura aprovadas; modelo comercial ainda pode mudar após integração.
- Candidato: Modelo plausível identificado, aguardando dimensionamento/ensaio.
- Candidato — compra bloqueada: Não emitir pedido antes do gate técnico indicado.
- TBD: Requisito funcional definido; fornecedor e part number não selecionados.
- TBD crítico: Item de segurança/desempenho; requer cálculo, desenho ou análise antes da seleção.
- Sob medida: Deve ser projetado/fabricado a partir de desenho liberado.
- Opcional / candidato: Equipamento de missão opcional, sujeito ao perfil operacional e orçamento.

# 2. Especificação técnica consolidada

Parâmetro | Valor / requisito
Tipo | UAV cargueiro/de resgate híbrido VTOL de asa fixa
Status | Configuração conceitual consolidada; não liberada para fabricação ou compra integral
Envergadura | 4,20 m
Comprimento | 2,85 m (envelope atual; requisito inicial 2,6–3,0 m)
Área alar | 2,604 m²
Corda raiz / ponta | 0,820 m / 0,420 m
Afilamento | 0,512
Corda aerodinâmica média | 0,6415 m
Alongamento geométrico | AR ≈ 6,77
Empenagem | Cauda em V, ângulo consolidado de 40°
Carga útil | Até 5 kg — meta
Alcance | 400 km — meta a validar por ensaio de consumo e reserva
Velocidade CFD de referência | 25 m/s, α = 0°
Centro de gravidade alvo | x ≈ 1,05–1,085 m; referência de momentos x = 1,07 m
Propulsão VTOL | 4 motores elétricos 12S em naceles inclináveis
Pivôs dianteiros | x = 0,600 m; inclinação de cruzeiro para frente: −90°
Pivôs traseiros | x = 2,000 m; inclinação de cruzeiro para trás: +90°
Propulsão de cruzeiro | Motor traseiro a gasolina em configuração pusher
Geração elétrica | Starter-generator dedicado; motores VTOL não são assumidos como geradores nesta revisão
MTOW | TBD — gate obrigatório antes da compra de motores, ESCs, pack, tilt, estrutura e paraquedas

# 3. Arquitetura operacional

Decolagem e pouso são verticais com quatro rotores elétricos. Depois de atingir altitude e condições de transição, o motor traseiro a gasolina é acionado e assume o cruzeiro. Um starter-generator dedicado realiza a partida e pode alimentar o barramento/recarregar a bateria dentro dos limites elétricos e térmicos. Nesta revisão, os quatro motores VTOL não são usados como geradores.

- Dianteiros: pivôs em x=0,600 m; inclinam para frente até −90° no cruzeiro.
- Traseiros: pivôs em x=2,000 m; inclinam para trás até +90° no cruzeiro.
- Cruzeiro: motor a gasolina traseiro em configuração pusher.
- Carga útil: meta de até 5 kg; alcance: meta de 400 km.

# 4. Intertravamento dos tilt-rotors

O movimento de uma nacele é proibido enquanto a hélice correspondente não estiver parada, indexada e protegida contra reenergização. A lógica deve ser independente por rotor e tolerante a uma falha simples detectável.

- Comandar torque zero e confirmar desligamento do ESC.
- Confirmar RPM abaixo do limite seguro por sensor independente.
- Indexar a hélice dentro da janela angular definida no CAD.
- Confirmar caminho livre e liberar a trava mecânica da posição atual.
- Mover a nacele com velocidade/torque monitorados.
- Engatar a trava mecânica da nova posição e confirmar com dois sinais coerentes.
- Somente então permitir nova energização do motor.

Falha ou discordância: interromper a transição, manter/retornar à última posição mecanicamente segura e bloquear a reenergização do rotor afetado. O mecanismo não pode depender apenas do torque de retenção do atuador.

# 5. Orçamento de massa e centro de gravidade

O MTOW ainda não está fechado. O alvo de CG é x≈1,05–1,085 m, com referência de momentos em x=1,07 m. O marcador antigo em x=1,35 m e massas históricas do documento Arduino não são válidos para liberação. A planilha de massa deve conter massa, tolerância e posição x/y/z de cada item, combustível em estados cheio/reserva/vazio e carga útil em todos os envelopes.

- Gate G1: nenhum conjunto VTOL, pack, tilt, estrutura ou paraquedas deve ser comprado antes do fechamento de MTOW/CG.
- Critério inicial do VTOL: empuxo total medido ≥1,5× o peso máximo de decolagem.

# 6. Energia e geração

A arquitetura conceitual usa barramento 12S. O pack 12S4P com 48 células P45B é apenas candidato: 43,2 V e 18 Ah nominais, cerca de 777,6 Wh e 3,31 kg somente em células. Interconexões, contenção, BMS/monitor, contatores, fusíveis e margem térmica aumentam massa e devem ser projetados por profissional qualificado.

- A aviónica essencial possui alimentação de reserva independente e OR-ing.
- O Raspberry Pi recebe DC/DC dedicado e redundante; não depende apenas da saída do power module.
- A regeneração do starter-generator deve limitar tensão/corrente e suportar rejeição súbita de carga.

# 7. Validação disponível e limitações

O caso CFD base usa OpenFOAM 14 a 25 m/s e α=0°, com 269.773 células. O resultado preliminar médio reportado entre passos 140–150 foi Cd≈0,06546, Cl≈−0,01247 e Cm≈0,01091. Como não há camadas de parede nem representação das hélices/esteiras, os números servem para verificar o fluxo de trabalho, não para congelar o projeto.

# 8. Gates de liberação

- G1 — Massa/CG: MTOW, centros de massa, combustível e carga útil fechados.
- G2 — VTOL: Empuxo, corrente, temperatura, vibração e falha de um motor demonstrados.
- G3 — Cruzeiro: Empuxo, consumo, partida em voo, alcance de 400 km e reserva demonstrados.
- G4 — Tilt: Pivôs, cargas, folgas, indexação, travas e análise de falhas aprovados.
- G5 — Energia: Pack, proteções, redundância e starter-generator validados.
- G6 — Estrutura: FEA, cargas limite/última e provas estáticas concluídas.
- G7 — Segurança: Paraquedas, failsafes, regulamentação e plano de ensaios aprovados.

# 9. Lista mestra de compras — 71 linhas

Cada linha possui ficha técnica individual na pasta “Data sheets”. Quantidade de materiais a granel e ferragens deve ser convertida em quantidade final após desenhos de fabricação.

ID | Categoria | Item | Qtd. | Maturidade | Candidato/modelo | Liberação
DS-001 | Aviónica | Controlador de voo | 1 | Arquitetura aceita | Holybro Pixhawk 6X | Revisão
DS-002 | Aviónica | Computador de missão | 1 | Arquitetura aceita | Raspberry Pi 5 — 8 GB | Revisão
DS-003 | Aviónica | Refrigerador do computador | 1 | Candidato | Raspberry Pi Active Cooler | Bloqueada
DS-004 | Aviónica | Módulo GNSS/RTK + magnetômetro | 1 | Candidato | Holybro H-RTK NEO-F9P + RM3100 | Bloqueada
DS-005 | Aviónica | Sensor de velocidade do ar + pitot | 1 | Candidato | Holybro MS5525 | Bloqueada
DS-006 | Aviónica | Altímetro laser | 1 | Candidato | LightWare SF11/C | Bloqueada
DS-007 | Missão | Câmera RGB | 1 | Candidato | Raspberry Pi Camera Module 3 Wide | Bloqueada
DS-008 | Missão | Câmera térmica | 1 | Opcional / candidato | Teledyne FLIR Boson 320 ou 640 | Bloqueada
DS-009 | Aviónica | Armazenamento de missão | 2 | TBD | microSD High Endurance ou NVMe industrial | Bloqueada
DS-010 | Aviónica | Buzzer e localizador | 1 | TBD | Buzzer ativo + beacon independente | Bloqueada
DS-011 | Aviónica | Módulo de relógio RTC | 1 | TBD | RTC industrial com bateria/supercapacitor | Bloqueada
DS-012 | Comunicação | Rádio telemetria de bordo | 1 | Candidato | RFD900x-BR | Bloqueada
DS-013 | Comunicação | Rádio telemetria de solo | 1 | Candidato | RFD900x-BR USB | Bloqueada
DS-014 | Comunicação | Conjunto de antenas e cabos RF | 1 kit | TBD | Antenas 900 MHz + cabos coaxiais | Bloqueada
DS-015 | Comunicação | Modem 4G | 1 | Candidato | Waveshare SIM7600G-H 4G HAT | Bloqueada
DS-016 | Comunicação | Antenas LTE/GNSS do modem | 1 kit | TBD | Antenas compatíveis com SIM7600 | Bloqueada
DS-017 | Propulsão VTOL | Motor elétrico de sustentação | 4 | Candidato — compra bloqueada | T-Motor U10 II KV100 | Bloqueada
DS-018 | Propulsão VTOL | ESC dos motores de sustentação | 4 | Candidato — compra bloqueada | T-Motor ALPHA 80A 12S | Bloqueada
DS-019 | Propulsão VTOL | Hélice VTOL CW 30×10,5 | 2 + 1 reserva | Candidato — compra bloqueada | T-Motor G30×10.5 CW | Bloqueada
DS-020 | Propulsão VTOL | Hélice VTOL CCW 30×10,5 | 2 + 1 reserva | Candidato — compra bloqueada | T-Motor G30×10.5 CCW | Bloqueada
DS-021 | Tilt-rotor | Atuador de inclinação da nacele | 4 | TBD crítico | Atuador eletromecânico industrial com feedback absoluto | Bloqueada
DS-022 | Tilt-rotor | Trava mecânica da nacele | 4 | TBD crítico | Pino/trava fail-safe com sensor duplo | Bloqueada
DS-023 | Tilt-rotor | Sensor de indexação/parada da hélice | 4 | TBD crítico | Encoder/Hall redundante | Bloqueada
DS-024 | Tilt-rotor | Mancais e eixo do pivô | 4 kits | TBD crítico | Rolamentos selados + eixo 7075/aço | Bloqueada
DS-025 | Propulsão cruzeiro | Motor a gasolina pusher | 1 | Candidato — compra bloqueada | DLE35RA | Bloqueada
DS-026 | Propulsão cruzeiro | Hélice pusher | 2 | TBD crítico | 19×8 ou 20×8 pusher compatível | Bloqueada
DS-027 | Propulsão cruzeiro | Servo de aceleração | 1 | TBD | Servo HV metal gear | Bloqueada
DS-028 | Propulsão cruzeiro | Módulo de corte da ignição | 1 | TBD crítico | Kill switch optoisolado | Bloqueada
DS-029 | Propulsão cruzeiro | Sensor de RPM do motor térmico | 1 | TBD | Sensor Hall/óptico isolado | Bloqueada
DS-030 | Propulsão cruzeiro | Motor elétrico starter-generator | 1 | TBD crítico | BLDC dimensionado para partida e geração | Bloqueada
DS-031 | Propulsão cruzeiro | Controlador bidirecional starter-generator | 1 | TBD crítico | Inversor/retificador BLDC bidirecional | Bloqueada
DS-032 | Propulsão cruzeiro | Embreagem/roda livre e transmissão | 1 kit | TBD crítico | Roda livre + correia/engrenagem | Bloqueada
DS-033 | Combustível | Tanque ou bladder de combustível | 1 | TBD crítico | Capacidade geométrica inicial 4 L | Bloqueada
DS-034 | Combustível | Kit de linhas, filtro, clunk e respiro | 1 kit | TBD | Componentes compatíveis com gasolina | Bloqueada
DS-035 | Combustível | Válvula de corte de combustível | 1 | TBD crítico | Válvula fail-safe compatível com gasolina | Bloqueada

ID | Categoria | Item | Qtd. | Maturidade | Candidato/modelo | Liberação
DS-036 | Combustível | Sensor de nível/fluxo de combustível | 1 | TBD | Sensor compatível com gasolina | Bloqueada
DS-037 | Energia | Célula Li-ion 21700 | 48 | Candidato — compra bloqueada | Molicel INR-21700-P45B; pack conceitual 12S4P | Bloqueada
DS-038 | Energia | BMS/monitor de células 12S | 1 | TBD crítico | BMS aeronáutico ou monitor independente | Bloqueada
DS-039 | Energia | Contator principal HV | 1 | TBD crítico | Contator DC ≥60 V | Bloqueada
DS-040 | Energia | Circuito de pré-carga | 1 | TBD crítico | Resistor + relé/contator de pré-carga | Bloqueada
DS-041 | Energia | Fusível principal HV | 1 + 2 reservas | TBD crítico | Fusível DC aeronáutico/EV | Bloqueada
DS-042 | Energia | Distribuidor/barramento de potência HV | 1 | Sob medida | PDB/busbar 12S | Bloqueada
DS-043 | Energia | Módulo de medição de potência | 1 | Candidato | Holybro PM08-CAN ou solução equivalente | Bloqueada
DS-044 | Energia | Conversor DC/DC 5 V 5 A isolado | 2 | TBD crítico | Conversores industriais redundantes | Bloqueada
DS-045 | Energia | Conversor DC/DC 12 V | 1 | TBD | Conversor industrial 12S→12 V | Bloqueada
DS-046 | Energia | Bateria reserva de aviónica | 1 | TBD crítico | Pack LiFePO4 independente | Bloqueada
DS-047 | Energia | Módulo ideal-diode/OR-ing | 1 | TBD crítico | OR-ing de duas fontes | Bloqueada
DS-048 | Energia | Conectores antifaísca HV | 1 kit | TBD | AS150 ou equivalente qualificado | Bloqueada
DS-049 | Energia | Cabos de potência e sinal | 1 lote | TBD | Cabos flexíveis aeronáuticos | Bloqueada
DS-050 | Energia | Sensores de temperatura | 8 | TBD | NTC/PT1000 digitais/analógicos | Bloqueada
DS-051 | Controles | Servo de aileron HV | 2 + 1 reserva | TBD crítico | Servo digital industrial metal gear | Bloqueada
DS-052 | Controles | Servo de ruddervator da cauda V | 2 + 1 reserva | TBD crítico | Servo digital industrial metal gear | Bloqueada
DS-053 | Controles | Servo de porta/liberação de carga | 1 | TBD | Servo ou atuador com trava | Bloqueada
DS-054 | Controles | Hinges, horns e pushrods | 1 kit | TBD | Ferragens aeronáuticas | Bloqueada
DS-055 | Estrutura | Longarinas/tubos de fibra de carbono | 1 lote | TBD crítico | Tubos/pultrudados com certificado | Bloqueada
DS-056 | Estrutura | Tecido de carbono e epóxi | 1 lote | TBD | Sistema laminado aeronáutico | Bloqueada
DS-057 | Estrutura | Núcleo de espuma/honeycomb | 1 lote | TBD | PVC estrutural ou honeycomb | Bloqueada
DS-058 | Estrutura | Compensado aeronáutico/firewall | 1 lote | TBD crítico | Compensado birch aeronáutico | Bloqueada
DS-059 | Estrutura | Perfis/chapas de alumínio 7075-T6 | 1 lote | TBD crítico | Material com certificado | Bloqueada
DS-060 | Estrutura | Fixadores e porcas travantes | 1 lote | TBD | Classe aeronáutica, tamanhos por desenho | Bloqueada
DS-061 | Estrutura | Coxins antivibração | 1 kit | TBD | Isoladores motor/aviónica | Bloqueada
DS-062 | Estrutura | Trem de pouso/skids | 1 conjunto | TBD crítico | Compósito/alumínio absorvente | Bloqueada
DS-063 | Estrutura | Proteção térmica e corta-fogo | 1 kit | TBD crítico | Manta/barreira compatível com gasolina | Bloqueada
DS-064 | Segurança | Sistema de paraquedas | 1 | TBD crítico | Fruity Chutes ou equivalente dimensionado pelo MTOW | Bloqueada
DS-065 | Segurança | Controlador de terminação/recuperação | 1 | TBD crítico | Controlador independente | Bloqueada
DS-066 | Segurança | Luzes de navegação e anticolisão | 1 kit | TBD | LEDs aeronáuticos de alta intensidade | Bloqueada
DS-067 | Solo | Carregador/balanceador 12S | 1 | TBD crítico | Carregador CC/CV com logging | Bloqueada
DS-068 | Solo | Gabinete de armazenamento de baterias | 1 | TBD crítico | Armário resistente ao fogo ventilado | Bloqueada
DS-069 | Solo | Bancada de empuxo e célula de carga | 1 | TBD crítico | Bancada ≥15 kgf por motor | Bloqueada
DS-070 | Solo | Tacômetro e instrumentos elétricos | 1 kit | TBD | Tacômetro óptico + analisador DC | Bloqueada
DS-071 | Solo | Estação de controle em solo | 1 | TBD | Notebook robusto com Mission Planner/QGroundControl | Bloqueada

# 10. Rastreabilidade e fontes

Fontes principais: modelo FreeCAD atual, caso OpenFOAM atual, conversa de consolidação e documentação histórica do projeto Arduino. Quando houve conflito, prevaleceu a geometria paramétrica atual; números antigos de asa/massa foram tratados como superados. Os links oficiais completos estão nas fichas técnicas individuais.

# 11. Próximas decisões

- Preencher orçamento de massa/CG com tolerâncias.
- Construir bancada e medir os conjuntos de propulsão.
- Dimensionar mecanicamente cada pivô/trava e congelar a janela de indexação das pás.
- Fechar o balanço de energia, a estratégia de recarga e o pack.
- Atualizar CFD e executar FEA/provas estruturais.
- Revisar a BOM após cada gate e somente então liberar part numbers.

Documento preliminar — compra condicionada aos gates técnicos |

TECH SPEC — UAV HÍBRIDO VTOL | REV. A

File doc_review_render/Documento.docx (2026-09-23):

Figuras

Links úteis:

- Instalando Blync: https://www.youtube.com/watch?v=UF79_MTizQA&t=209s
- Documentação módulo serial: https://tinyurl.com/y2svtas5
- Tutorial sensor de Corrente: http://henrysbench.capnfatz.com/henrys-bench/arduino-current-measurements/ta12-100-arduino-ac-current-sensor-tutorial/ (http://henrysbench.capnfatz.com/henrys-bench/arduino-current-measurements/ta12-100-arduino-ac-current-sensor-tutorial/)
- Ligação para SD NANO http://lab.dejaworks.com/arduino-nano-sd-card-connection/
- Ligação UNO: https://create.arduino.cc/projecthub/electropeak/sd-card-module-with-arduino-how-to-read-write-data-37f390 (https://create.arduino.cc/projecthub/electropeak/sd-card-module-with-arduino-how-to-read-write-data-37f390)
- Balanca digital: https://forum.arduino.cc/t/collect-deformation-value-via-strain-gauge-with-hx711/984882
- Referências linguagem Arduino: https://www.arduino.cc/reference/en/
- Gravando Boot Loader no Arduino Pro MINI: https://antonhensen.wordpress.com/2018/03/09/burning-a-bootloader-on-an-arduino-pro-mini-using-an-arduino-uno/ (https://antonhensen.wordpress.com/2018/03/09/burning-a-bootloader-on-an-arduino-pro-mini-using-an-arduino-uno/)
- Calibrando o Sensor de Vibração: https://wired.chillibasket.com/2015/01/calibrating-mpu6050/
- ESP32 DHT11/DHT22 Web Server using Arduino IDE | Random Nerd Tutorials (https://randomnerdtutorials.com/esp32-dht11-dht22-temperature-humidity-web-server-arduino-ide/)
- ESP8266 DHT11/DHT22 Web Server Arduino IDE | Random Nerd Tutorials (https://randomnerdtutorials.com/esp8266-dht11dht22-temperature-and-humidity-web-server-with-arduino-ide/)

No Arduino IDE esp32 DEV Module, é o que melhor funciona.

- This chip has 2 cores
- Chip ID: 10384000
- ESP32 Chip model = ESP32-D0WDQ5 Rev 1
- This chip has 2 cores
- Chip ID: 10384000
- ESP32 Chip model = ESP32-D0WDQ5 Rev 1
- This chip has 2 cores
- Chip ID: 10384000
- ESP32 Chip model = ESP32-D0WDQ5 Rev 1
- This chip has 2 cores
- Chip ID: 10384000
- ESP32 Chip model = ESP32-D0WDQ5 Rev 1
- This chip has 2 cores
- Chip ID: 10384000
- ESP32 Chip model = ESP32-D0WDQ5 Rev

## 1 Documentação Fonte de Bancada

https://pt.aliexpress.com/item/1005005991522381.html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 (https://pt.aliexpress.com/item/1005005991522381.html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)1&pdp_npi=4%40dis%21BRL%2159.19%2118.99%21%21%2166.67%2121.39%21%402101c59817356109264037568e20de%21120 (https://pt.aliexpress.com/item/1005005991522381.html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)

00035209592184%21sea%21BR%212343346147%21X&curPageLogUid=WWlDVLZVi1WW&utparam- (https://pt.aliexpress.com/item/1005005991522381.html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)url=scene%3Asearch%7Cquery_from%3A (https://pt.aliexpress.com/item/1005005991522381.html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)

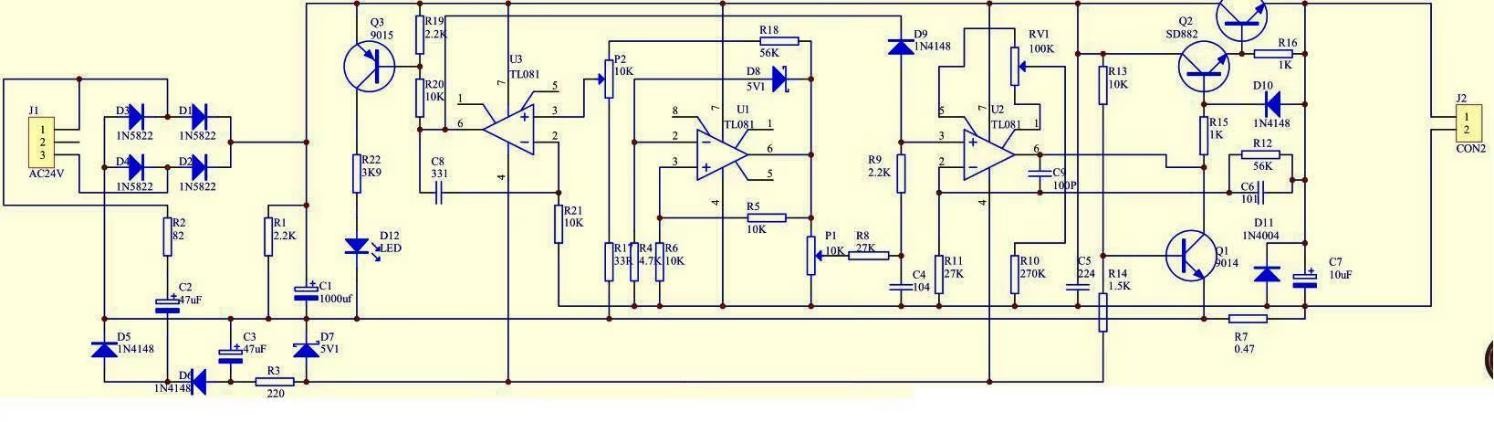
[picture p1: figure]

Figura 1 – Diagrama esquemático da Fonte de Bancada

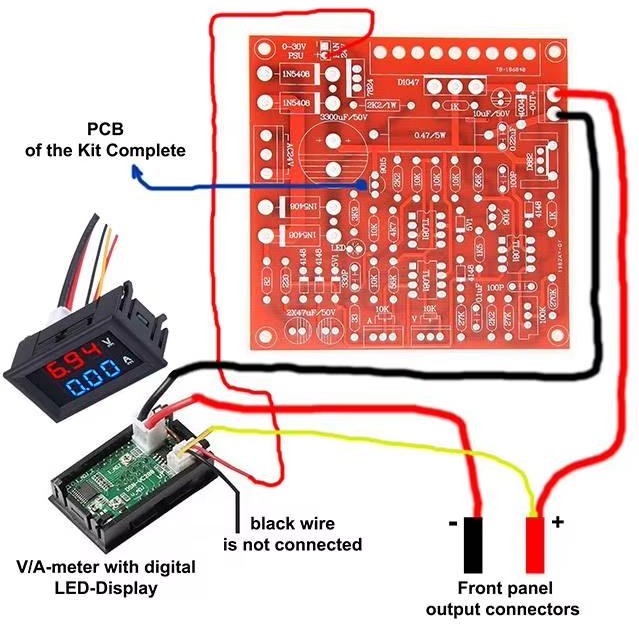
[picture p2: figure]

Figura 2 - Esquema de Ligação da Fonte de Bancada

Figura 3 - Serigrafia da placa da fonte de bancada

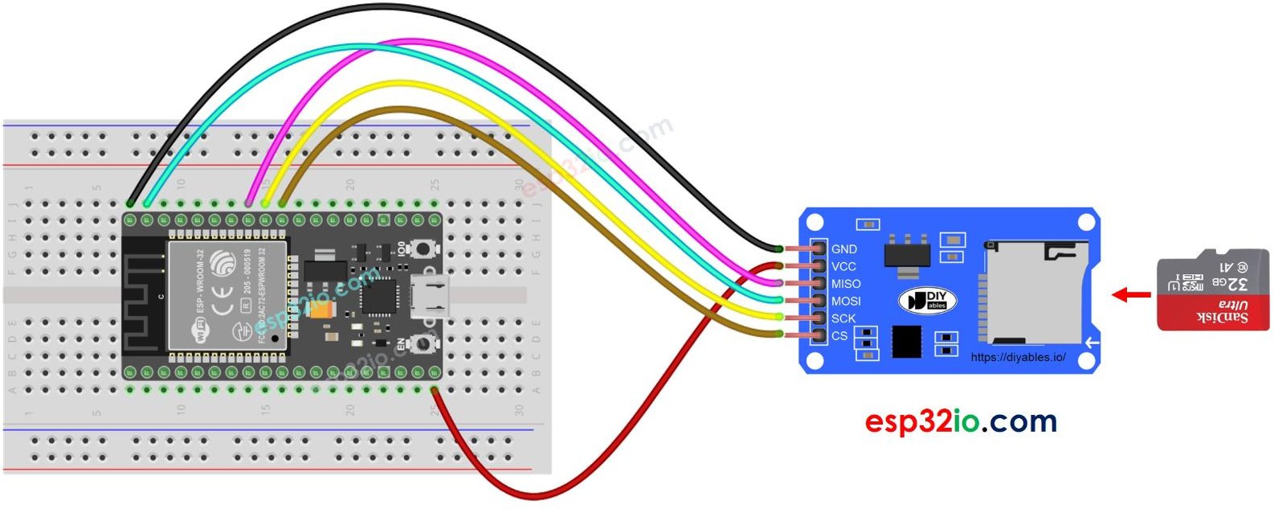
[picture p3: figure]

Figura 4 - esquema de ligação ESP32 - SD Card

https://esp32io.com/tutorials/esp32-sd-card

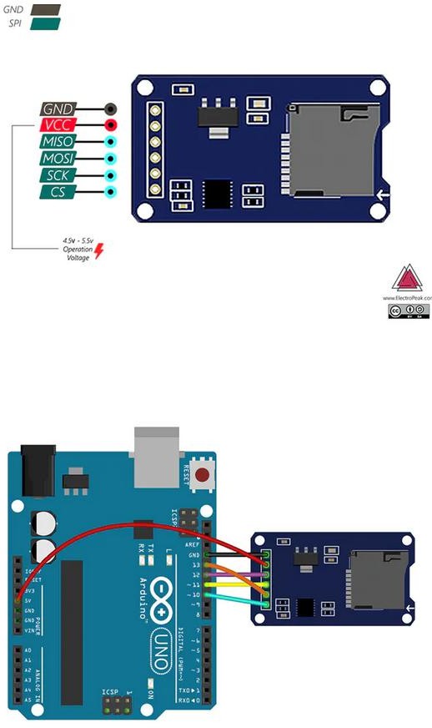
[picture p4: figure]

Figura 5 - Esquema de Ligação Módulo de Cartão Micro SD - Arduino

- http://arduino.esp8266.com/stable/package_esp8266com_index.json em Preferências do Arduino IDE

## 2 Módulo ESP8266

Para configurar o módulo ESP8266

https://blogmasterwalkershop.com.br/embarcados/esp8266/upgrade-de-firmware-do-wifi-esp8266-esp-01-atraves-do-arduino-e-conversor-usb-serial/ (https://blogmasterwalkershop.com.br/embarcados/esp8266/upgrade-de-firmware-do-wifi-esp8266-esp-01-atraves-do-arduino-e-conversor-usb-serial/)

Para setar a velocidade da porta serial: AT+UART_DEF=9600,8,1,0,0 (melhor para usar o Arduino como Wi-Fi)

Usando o ESP01 e o Arduino para enviar a temperatura ambiente

https://blogmasterwalkershop.com.br/blynk/blynk-controle-do-arduino-via-wifi-com-esp8266-esp-01/

- Para instalar ESP01s: https://www.youtube.com/watch?v=TgxrfagXROk
- Para instalar a placa ESP8266 no gerenciador de placas:

Figura 6 - Pinagem ESP8266

(Blynk) Display Labeled Value Graph (ESP-01 Standalone)

https://m.blog.naver.com/PostView.nhn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 om%2F (https://m.blog.naver.com/PostView.nhn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)

Muito Legal, mas ver depois:

- https://thingsboard.io/docs/user-guide/install/windows/
- https://www.instructables.com/id/Temperature-and-Humidity-Meter-With-Blynk-App/

habilitando o reed Suich: https://diyi0t.com/reed-switch-tutorial-for-arduino-and-esp8266/

## 3 Sensor de Abertura de porta

int digitalPin = 8; // KY-025 digital interface int digitalVal; // digital readings

void setup ()

{

pinMode(digitalPin, INPUT);

Serial.begin(9600);

}

void loop ()

{

// Read the digital interface digitalVal = digitalRead(digitalPin);

Serial.println(digitalVal); // print digital value delay(100);

}

Para usar o Eclipse como editor de Código:

https://www.digikey.com/en/maker/blogs/2018/how-to-program-arduino-with-eclipse

## 4 Protótipo usando ESP32

Cada fornecedor de ESP32 tem uma placa diferente, verificar a pinagem antes de ligar, o que estamos utilizando neste protótipo é o apresentado na Figura 4-1.

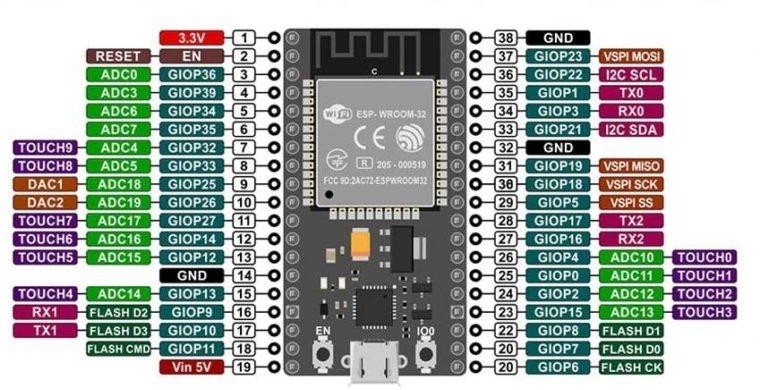
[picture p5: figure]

https://randomnerdtutorials.com/esp32-pinout-reference-gpios/

Figura 4-1 - Referência para Pinos WROOM-ESP32

Para utilizar a placa ESP32, é necessário acessar o gerenciador de placas da IDE do Arduino e adicionar a string, como apresentado em (https://randomnerdtutorials.com/installing-the-esp32-board-in-arduino-ide-windows-instructions/ (https://randomnerdtutorials.com/installing-the-esp32-board-in-arduino-ide-windows-instructions/) )

Considerando a instalação para as placas ESP8266 e ESP 32, a string de placas adicionais deve ficar como apresentado:

https://raw.githubusercontent.com/espressif/arduino-esp32/gh-pages/package_esp32_index.json, http://arduino.esp8266.com/stable/package_esp8266com_index.json

É necessário reiniciar a IDE para que as alterações sejam consideradas.

Selecionar ESP32 Dev Module, como apresentado na Figura 4-2:

Figura 4-2 - Seleção de Placa na IDE

#### 4.1 Exemplos para construção:

- Relógio com NTP e OLED: https://www.electronics-lab.com/project/network-clock-using-esp8266-oled-display/ (https://www.electronics-lab.com/project/network-clock-using-esp8266-oled-display/)

#### 4.2 Artigos úteis:

- ESP32 Useful Wi-Fi Library Functions: https://randomnerdtutorials.com/esp32-useful-wi-fi-functions-arduino/ (https://randomnerdtutorials.com/esp32-useful-wi-fi-functions-arduino/)

## 5 Sensor de temperatura e WEMO DI MINI

ligando o módulo SIM800L Usando o WEMO D1 MINI

Referências:

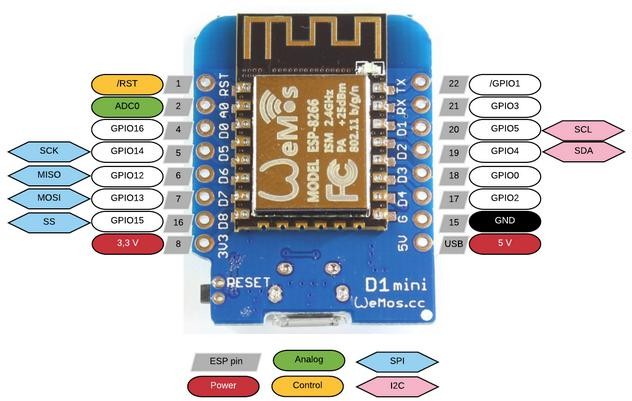
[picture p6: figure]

Figura 3 - Pinagem ESP8266 WEMOS

Fonte: https://github.com/OfficineArduinoTorino/RuralHack/issues/1

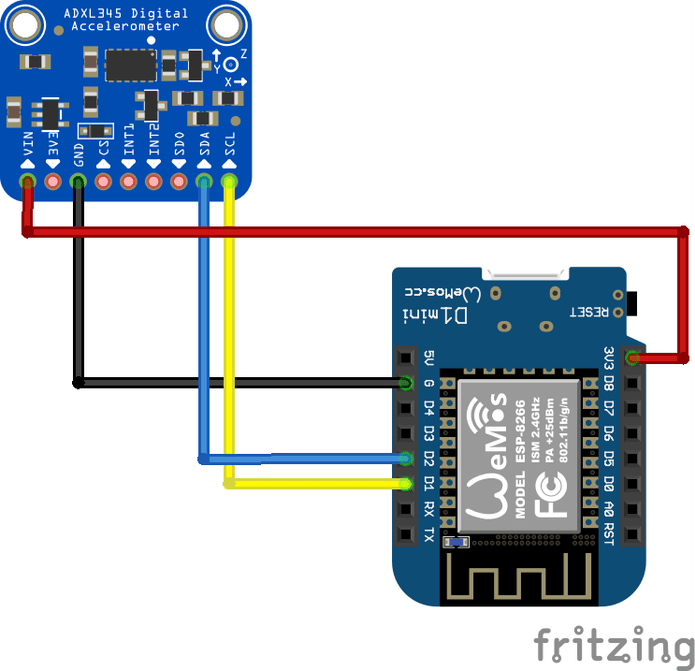
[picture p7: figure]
wemos-adxl345_bb

Figura 4 - Esquema de Ligação WEMOS ESP8266 com Acelerômetro ADXL345

http://www.esp8266learning.com/esp8266-lsm6ds3-accelerometer-gyroscope-example.php#codesyntax_1

https://create.arduino.cc/projecthub/electropeak/determining-the-pressure-and-altitude-using-gy-68-bmp180-and-93fd6f

https://www.mrwatt.eu/en/content/dht11-sensor-data-to-thingspeak-using-a-wemos-d1

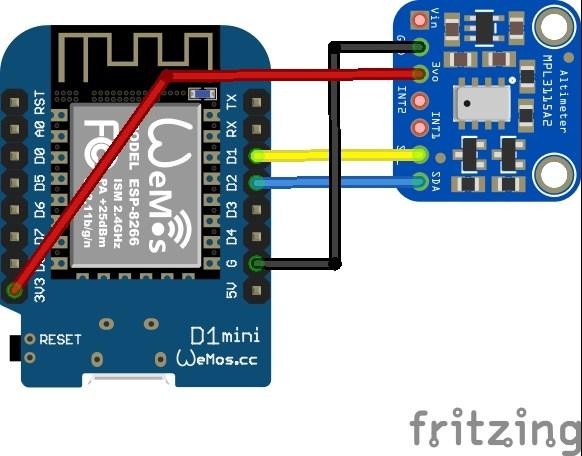
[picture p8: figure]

Figura 5 - Esquema de Ligação do ESP8266 WEMOS com Altímetro

https://simplycodebased.org/arduino/arduino-gy-68-barometer-hook-up-guide/

Ligando o Sensor de Pressão Barométrica ao Arduino

https://www.instructables.com/id/GY-68-BMP180-Barometric-Pressure-Breakout-Board-Tu/

https://learn.sparkfun.com/tutorials/bmp180-barometric-pressure-sensor-hookup-

Ligando Display Oled

https://www.youtube.com/watch?v=TPh72DtgWB0

Problemas de memória depois que inseri a rotina do Cartão, desabilitei então diversas variáveis que não eram necessárias.

São elas:

- Variáveis de gyro do giroscópio
- Índice de calor dos sensores de temperatura
- Temperatura do sensor de pressão barométrica
- Humidade do compressor

https://create.arduino.cc/projecthub/jeffpar0721/add-wifi-to-arduino-uno-663b9e

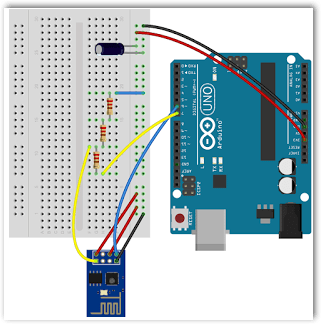
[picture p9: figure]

http://onlineshouter.com/top-5-ways-wire-esp8266-module-arduino-uno-board/

#### 5.1 Instalando o DRIVER USB

Se a IDE do Arduino não reconhecer a porta USB conectada no ESP32:

https://www.robocore.net/tutoriais/instalando-driver-do-nodemcu

Tutorial para AWS:

http://iotreta.com/DiretoParaAmazon/

https://www.guru99.com/download-install-node-js.html#1

https://nodered.org/docs/getting-started/windows

node-red

http://localhost:1880

para carregar: apertar o botão 1O0 após aparecer a mensagem de carregando na IDE Acessando o servidor NTP

https://lastminuteengineers.com/esp8266-ntp-server-date-time-tutorial/

https://randomnerdtutorials.com/esp32-useful-wi-fi-functions-arduino/

## 6 Arduino UNO + DHT 11

Monitorando Temperatura e Umidade com o sensor DHT11 - FilipeFlop (https://www.filipeflop.com/blog/monitorando-temperatura-e-umidade-com-o-sensor-dht11/)

## 7 ESP01 + DHT 11

Instalando aplaca: Setting Up the Arduino IDE to Program the ESP8266-01 : 3 Steps - Instructables (https://www.instructables.com/Setting-Up-the-Arduino-IDE-to-Program-the-ESP8266-/)

Gravando: Gravando o ESP8266-01 na IDE Arduino - Embarcados (https://www.embarcados.com.br/gravando-o-esp8266-01-na-ide-arduino/)

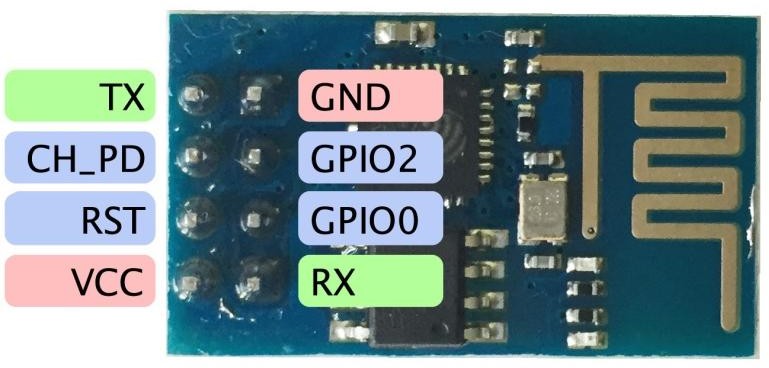
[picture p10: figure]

Figura 7-1 - pin out ESP01

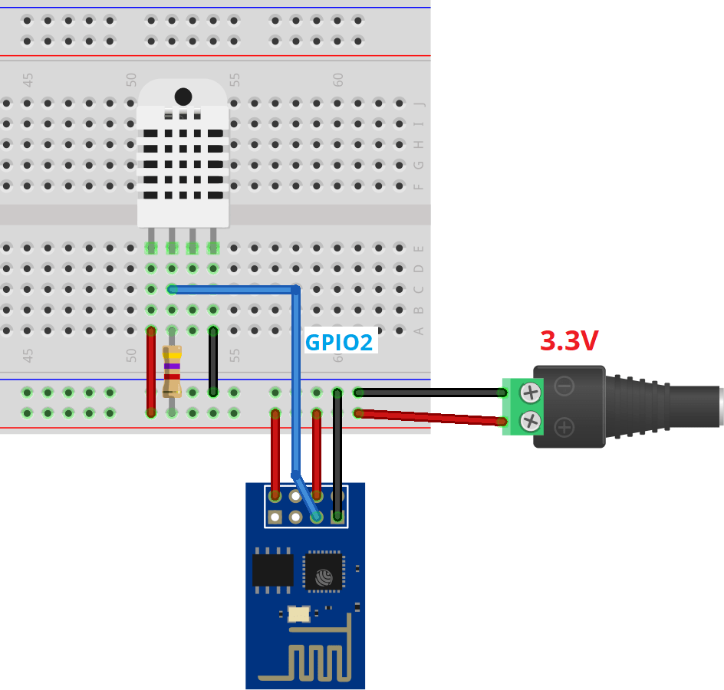
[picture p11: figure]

ESP8266 Temperature / Humidity Webserver with a DHT11 sensor | Elec-Cafe.Com (https://www.elec-cafe.com/esp8266-temperature-humidity-webserver-with-a-dht11-sensor/)

Mapping Household Temperature Flow with Cheap Sensors - Arduino Project Hub (https://create.arduino.cc/projecthub/humblehacker/mapping-household-temperature-flow-with-cheap-sensors-6a36c3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)

ESP-01 and DHT11 Temperature and Humidity Server (swampsoft.org) (http://www.swampsoft.org/esp/esp01-temp-humidity/)

Para programar o ESP01 → PROB

Para rodar →UART

## 8 Prot_tipo_03_WEMOS

Estação meteorológica com DHT11 e BMP180

Ainda falta entender a diferença entre pressão absoluta e relativa, bem como o cálculo da altitude

https://www.filipeflop.com/blog/como-enviar-dados-do-esp8266-para-o-google-sheets/

https://diyi0t.com/esp8266-wemos-d1-mini-tutorial/

Selecionar: LOLIN(WEMOS) D1 R2 & mini, e porta Dxx

## 9 Projeto Medidor de Frequência Cardíaca - Arduino Pro MINI

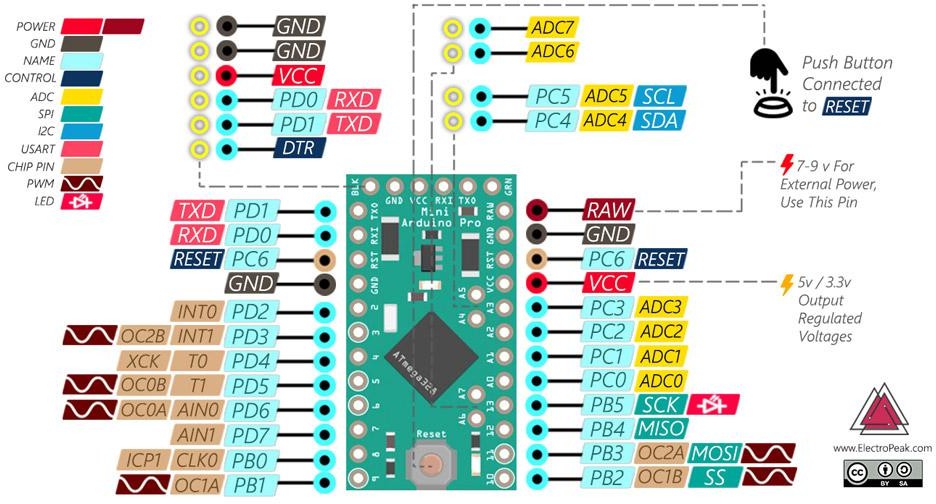
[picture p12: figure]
Arduino Buying Guide-Arduino Pro MINI pinout

Figura 9-1 - Pin out Arduino pro mini

## 10 Primeiros Passos com VS Code

Após um certo uso com a Arduino IDE, a coisa ficou complexa demais pra podermos continuar utilizando uma IDE sem debuger, além de - sabe-se la porque – a IDE ficou absurdamente lenta para compilar, levantando-se mais de 10min para um código de pouco mais de 30linhas.

- Baixar o VS code
- Instalar o Arduino Extension

https://learn.sparkfun.com/tutorials/efficient-arduino-programming-with-arduino-cli-and-visual-studio-code/all

#### 10.1 Configurando o VS Code

Output path:

Figura 10-1 - configurar saída

Fonte: https://www.tips.net.br/Tips/Detail/349eab4c-3117-4385-a16b-da74317e2a1c

Por que ficou esta barra branca horizontal? → para indicar que tem espaços à esquerda

## 11 Balança Digital com alimentador automático

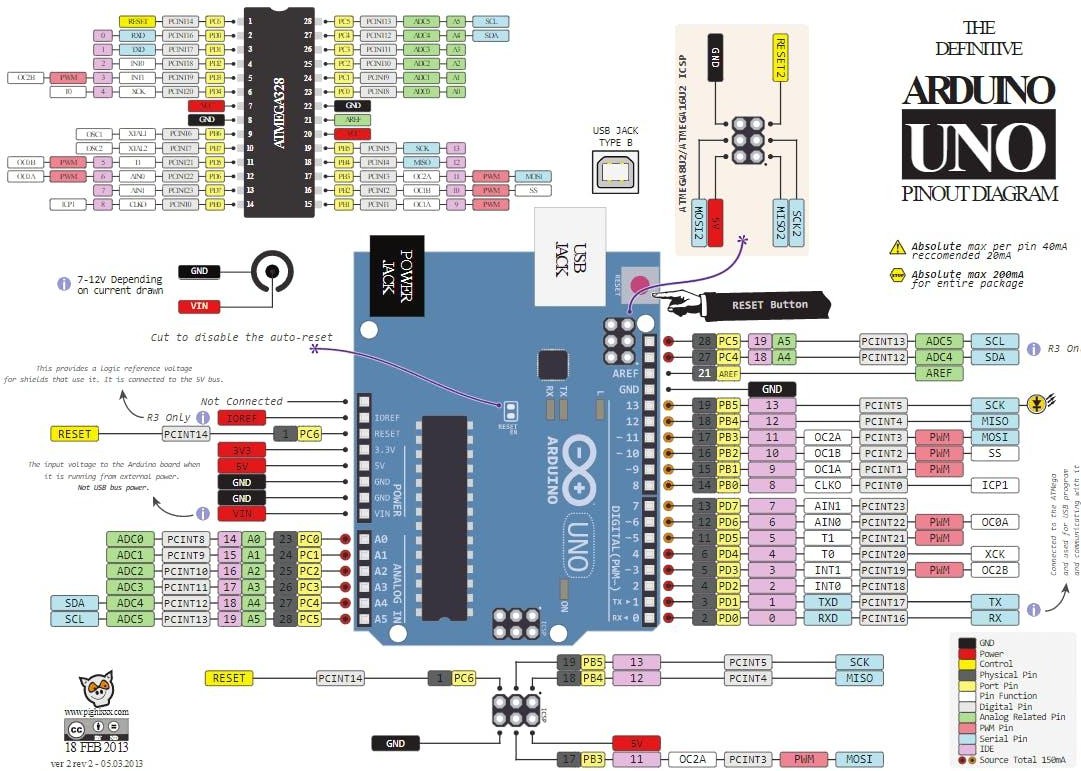
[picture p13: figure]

Figura 11-1 - Pinout – Arduino UNO R3

Fonte: https://www.circuito.io/blog/arduino-uno-pinout/

#### 11.1 Usando o LCD

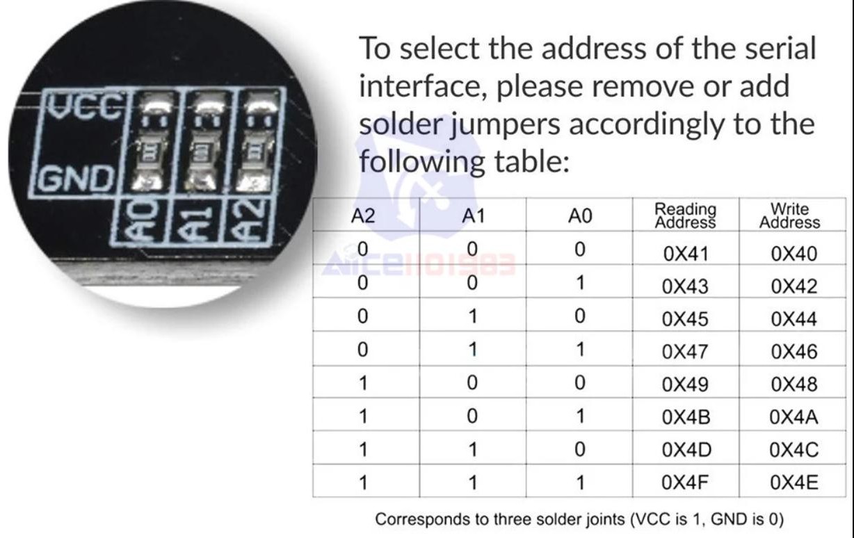
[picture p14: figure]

Modelo do I2C utilizado:

Mcp23017 12864 128*64 lcd i2c iic twi spi

#### 11.2 Bibliotecas:

- LCD Driver Module based on the chip MCP23017:

https://github.com/ATrappmann/LiquidCrystal_MCP23017_I2C

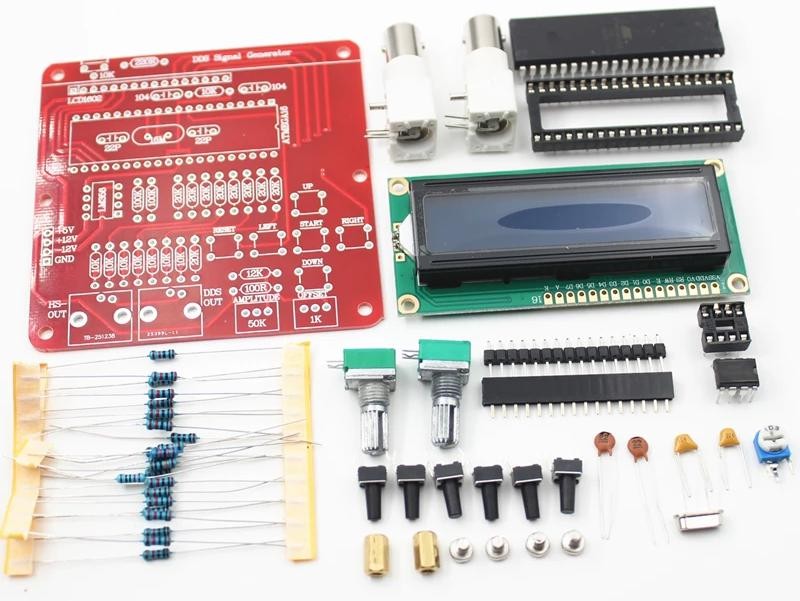
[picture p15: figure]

https://lastminuteengineers.com/drv8825-stepper-motor-driver-arduino-tutorial/

## 12 IPSC Soot Timer

Este projeto permite ao atirador contar seus tiros, o tempo entre eles, e assim melhorar e comparar sua performance com a de outros atiradores.

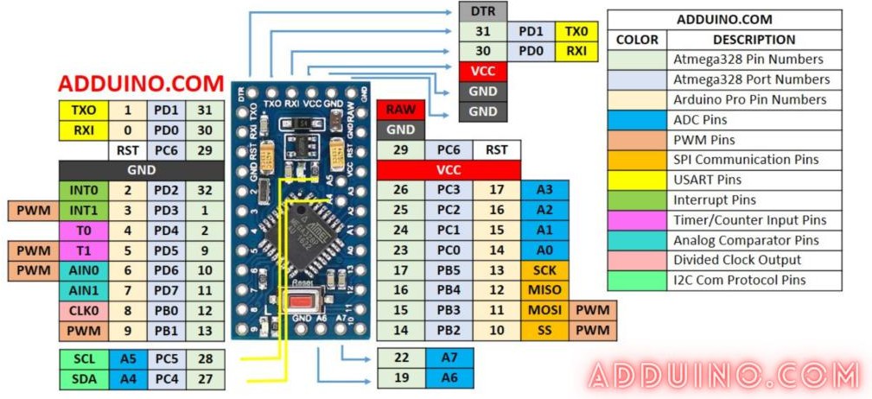
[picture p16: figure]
Introduction to Arduino Pro Mini (AVR Atmel Atmega328p)

Figura 12-1 – Pin out Arduino Pro mini

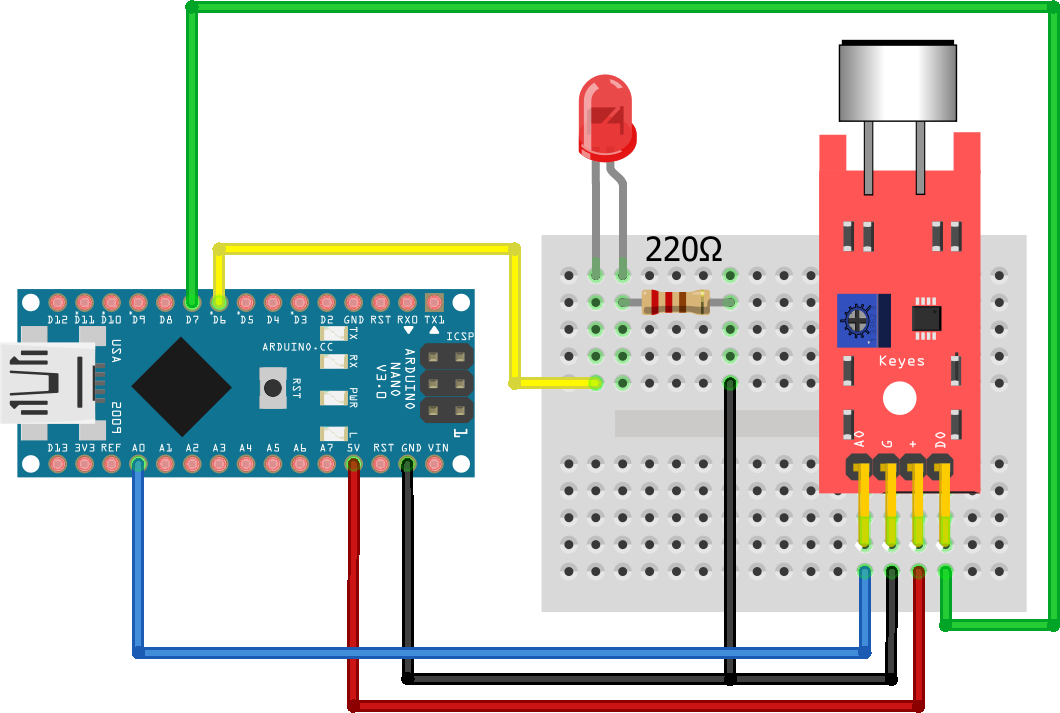
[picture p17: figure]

Figura 12-2 – esquema de ligação do sensor de som

Exemplo de código: https://diyi0t.com/sound-sensor-arduino-esp8266-esp32/

D:\OneDrive\Documentos\Arduino\ → libraries ondeficam as bibliotecas do arduino

<MenuSystem.h> v. 2.1.1

<Chrono.h> v. 1.0.0

<PGMWrap.h> v. 1.0.0

<EEWrap.h> v. 1.0.0

<Adafruit_RGBLCDShield.h> v.1.0.1

https://www.arduino.cc/en/Tutorial/BuiltInExamples/Button

Case: https://www.stlfinder.com/model/shot-timer-case-TTvgOugl/1543395/

https://create.arduino.cc/projecthub/michi4/lcd-menu-tutorial-39173b

## 13 Sensor de movimento para Armas

Vamos usar M5Stamp C3, com wifi e bluetooh

https://www.youtube.com/watch?v=mVglZVf84V0

Driver installation: https://docs.m5stack.com/en/core/stamp_c3

Getting Start: https://www.youtube.com/watch?v=Onsji41S9hE

URL para Placa: https://raw.githubusercontent.com/espressif/arduino-esp32/gh-pages/package_esp32_dev_index.json (https://raw.githubusercontent.com/espressif/arduino-esp32/gh-pages/package_esp32_dev_index.json)

https://docs.m5stack.com/en/core/stamp_c3

#### 13.1 Uma segunda opção é utilizar o LILYGO® T-OI ESP8266

http://www.lilygo.cn/prod_view.aspx?TypeId=50033&Id=1234&FId=t3:50033:3

http://www.lilygo.cn/prod_view.aspx?TypeId=50033&Id=1234&FId=t3:50033:3

http://www.lilygo.cn/prod_view.aspx?TypeId=50033&Id=1234&FId=t3:50033:3

Entretanto, este módulo é um pouco maior que a primeira opção, mas tem como principal vantagem a opção para acoplar uma bateira de Lítio diretamente na placa.

Vídeo conectando na web: https://www.youtube.com/watch?v=4v6c-KXsue0&t=1883s

Primeiros passos:

Configurando o Ambiente (IDE) do Arduino

https://randomnerdtutorials.com/installing-the-esp32-board-in-arduino-ide-windows-instructions/

Em Preferências, inserir estas duas URLs

https://raw.githubusercontent.com/espressif/arduino-esp32/gh-pages/package_esp32_index.json, http://arduino.esp8266.com/stable/package_esp8266com_index.json

Depois procurar por esp8266 e instalar.

Link do Código Fonte:

https://1drv.ms/u/s!AhgRkFtLPfx5wZRBXgcJJndbKQlIgg?e=9QJhFB

Exemplo aplicação:

https://howtomechatronics.com/tutorials/arduino/arduino-and-mpu6050-accelerometer-and-gyroscope-tutorial/

## 14 Câmera para Caça

https://www.youtube.com/watch?v=aCeVsySh-v4

#### 14.1 Projeto para seguir um objeto com a Câmera

https://gitlab.com/tul.ishwa/projects/-/tree/main/obj_tracker_arduino

## 15 Placa com Display Integrado CH9102F 16MB

https://pt.aliexpress.com/item/1005005970553639.html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 Adapt=glo2bra (https://pt.aliexpress.com/item/1005005970553639.html)

https://www.youtube.com/playlist?list=PLss_FGfTlLApbrHcx3m6als8fU9_KHNjB

https://sites.google.com/site/jmaathuis/arduino/lilygo-ttgo-t-display-esp32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 (https://sites.google.com/site/jmaathuis/arduino/lilygo-ttgo-t-display-esp32?pli=1)

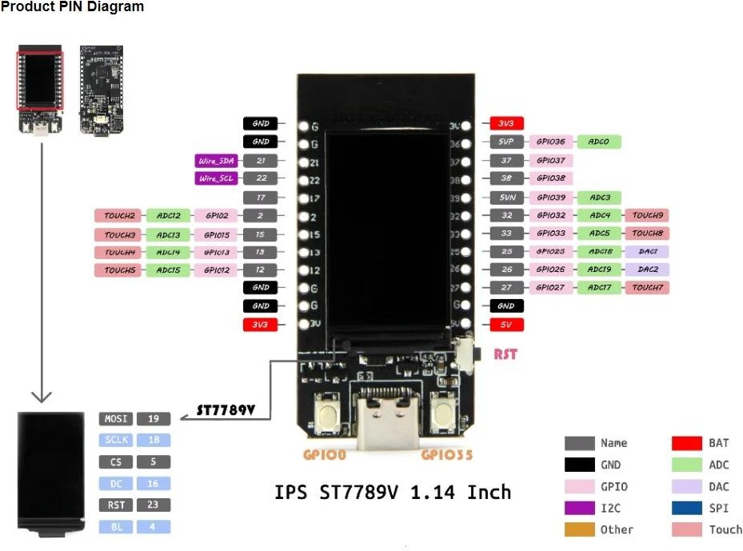
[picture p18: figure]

Figura 3 - Esquema de ligação e portas Tabela 1 - Especificações

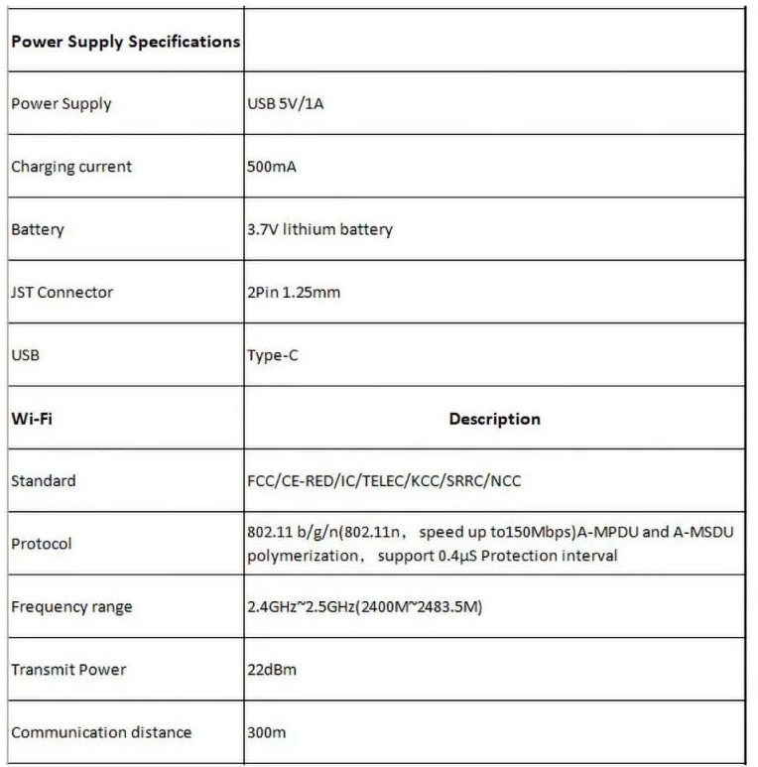
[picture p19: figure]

1.9 Display Module (170 x 320)

Figura 4 - Display 1.9 TFT - SPI

Tabela 2 - Data Sheet Display 1.9 TFT SPI

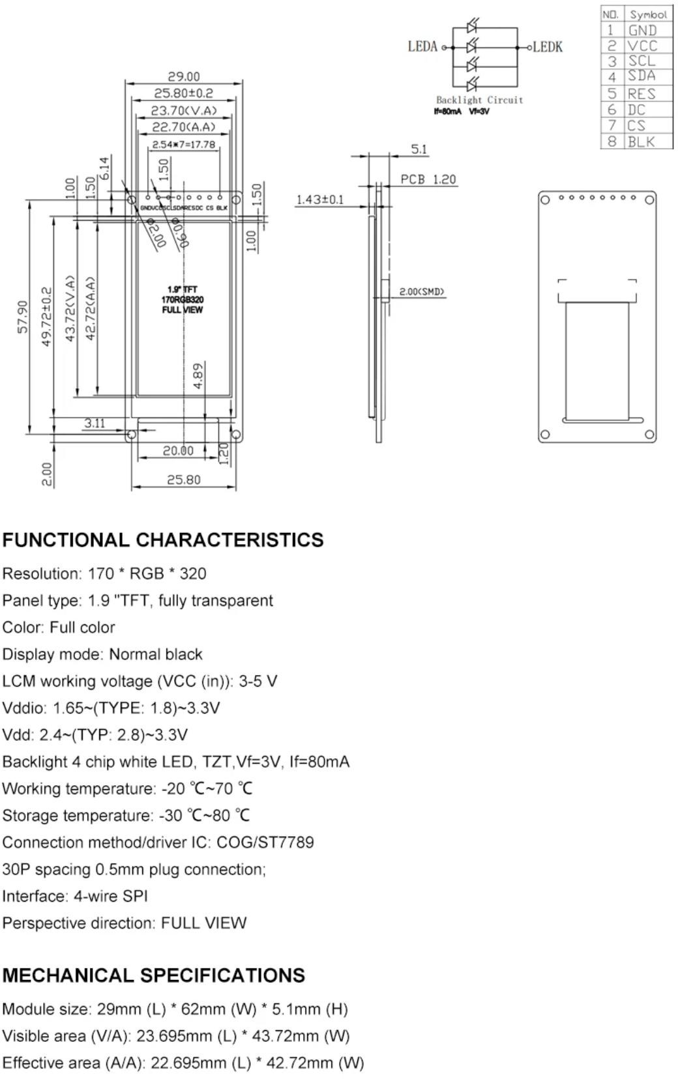
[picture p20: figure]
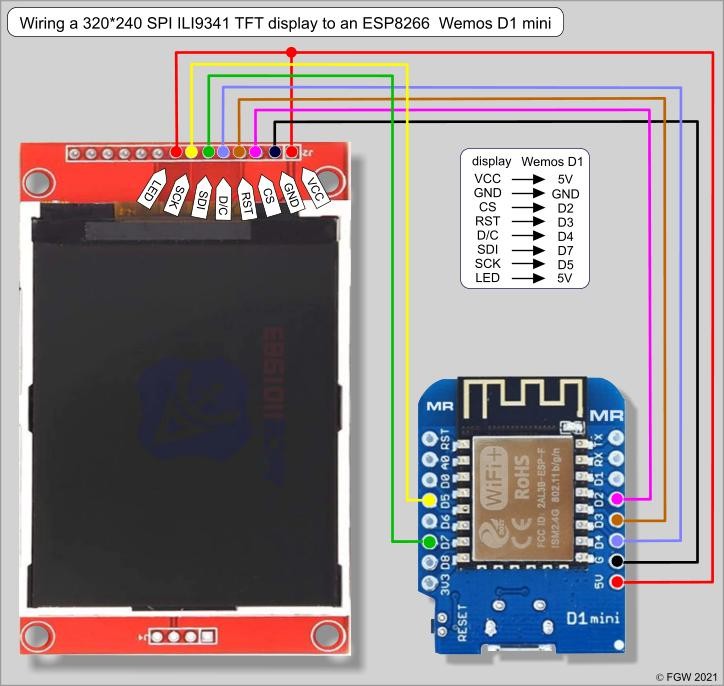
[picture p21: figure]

https://thesolaruniverse.wordpress.com/2021/05/02/wiring-an-ili9341-spi-tft-display-with-esp8266-based-microcontroller-boards-nodemcu-and-wemos-d1-mini/ (https://thesolaruniverse.wordpress.com/2021/05/02/wiring-an-ili9341-spi-tft-display-with-esp8266-based-microcontroller-boards-nodemcu-and-wemos-d1-mini/)

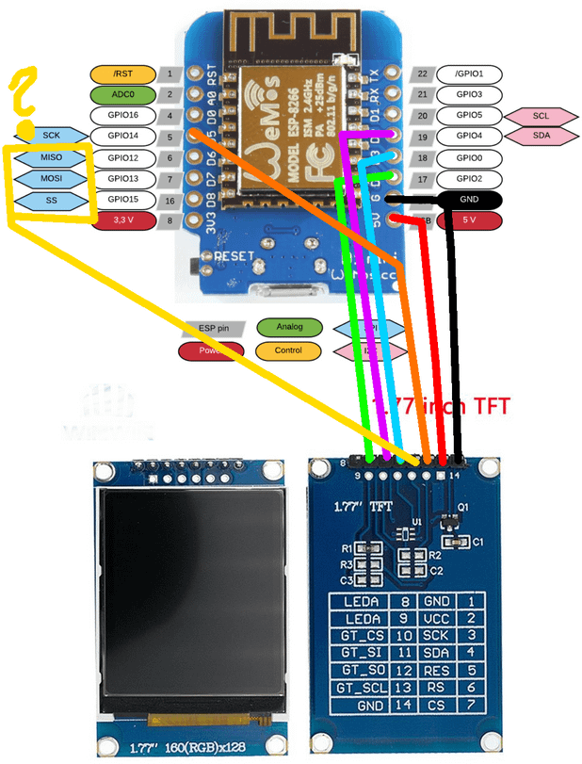
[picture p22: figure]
r/esp8266 - problem connecting spi tft screen to wemos d1 mini

https://www.reddit.com/r/esp8266/comments/xyti29/problem_connecting_spi_tft_screen_to_wemos_d1_mini/

## 16 Usando o Visual Studio com PlataformIO

https://www.youtube.com/watch?v=JmvMvIphMnY

## 17 PROJETO DE DRONE DE RESGATE

Autor: Nilberto

Data: 30 de junho de 2025 Links Úteis

- https://duino4projects.com/model-airplane-autopilot-using-arduino/
- https://projecthub.arduino.cc/suhaspn007/autopilot-drone-d3fa9f
- https://openscholarship.wustl.edu/cgi/viewcontent.cgi?article=1143&context=mems500
- https://www.youtube.com/watch?v=q6YIdY0WnOY

#### 17.1 Versão Baseada em Rasperry e Pixhawk

#### 17.2 Introdução

Este relatório apresenta a arquitetura de hardware e software de um drone de resgate, projetado para atuar em missões de busca e salvamento. O sistema integra uma controladora de voo Pixhawk com um Raspberry Pi 5, permitindo controle autônomo, visão computacional e comunicação em tempo real com a estação base.

#### 17.3 Objetivos do Projeto

- Desenvolver um drone capaz de realizar missões de resgate com autonomia.
- Integrar sensores e câmeras para navegação e detecção de vítimas.
- Estabelecer comunicação confiável com a estação base.
- Garantir segurança e redundância em situações críticas.

#### 17.4 Arquitetura de Hardware

Componente | Função
Raspberry Pi 5 | Processamento de imagem, IA, comunicação com Pixhawk
Pixhawk | Controle de voo, leitura de sensores, execução de missões
Câmera 12,3 MP | Captura de imagens e vídeo para análise e transmissão
GPS | Navegação e posicionamento geográfico
Motores + ESCs | Propulsão e controle de velocidade
Bateria Li-Po | Fonte de energia para todos os sistemas
Rádio 915 MHz | Telemetria e comunicação com a estação base
Wi-Fi / 4G | Transmissão de vídeo e controle remoto via internet

#### 17.5 Integração de Software

- Sistema Operacional: Raspberry Pi OS ou Ubuntu Server

###### Bibliotecas:

  - pymavlink: comunicação com Pixhawk
  - OpenCV: visão computacional
  - TensorFlow Lite: inferência de IA
  - GStreamer: streaming de vídeo
- Controladora de Voo: ArduPilot ou PX4, configurado via QGroundControl
- Protocolo de Comunicação: MAVLink

#### 17.6 Fluxo de Dados e Controle

#### 17.7 Descrição do Fluxograma

Você pode representar o seguinte fluxo com caixas e setas:

[Estação Base]

⇅ MAVLink [Raspberry Pi 5]

⇅ CSI / USB

[Câmera 12,3 MP]

⇅ UART / USB

[Pixhawk]

⇅ PWM / I2C

[Motores / Sensores / GPS]

###### Explicação:

- A estação base envia comandos ao Raspberry Pi.
- O Raspberry Pi processa dados da câmera e envia comandos ao Pixhawk.
- O Pixhawk controla os motores e lê sensores para manter o voo estável.
- Dados de telemetria e vídeo são enviados de volta à estação base.

#### 17.8 Segurança e Redundância

- Failsafe no Pixhawk: Retorno automático ao ponto de origem em caso de falha.
- Watchdog no Raspberry Pi: Reinício automático em caso de travamento.
- Gravação local: Logs de voo e imagens armazenados em cartão SD.

#### 17.9 Conclusão

A integração entre o Raspberry Pi 5 e o Pixhawk cria uma plataforma poderosa e flexível para drones de resgate. Com visão computacional, controle autônomo e comunicação robusta, o sistema é ideal para operações em ambientes desafiadores.

## 18 Versão Baseada em STM32 + Câmeras

Flight log:

- 30/07/2025 - Trabalhar com STM32 tem uma considerável curva de aprendizado. Fiquei a manhã toda para tentar compilar um “BLINK” sem sucesso. Há a necessidade de instalação de diversos sistemas.
  - STM32CubeProgrammer
  - STM32TrustedPackageCreator
  - STM32CubeMX
  - STM32CubeIDE 1.19.0

Existe a possibilidade de usar a interface do Arduino IDE e mesmo o VS code, mas sem sucesso ainda, nem mesmo a conexão eu tive sucesso. Vídeos na internet falam para instalar um boot loader, mas ainda sem sucesso.

#### 18.1 Introdução

Este relatório apresenta uma versão simplificada e didática de um drone de resgate, utilizando um microcontrolador STM32 e uma câmera embarcada. O objetivo é fornecer uma base acessível para aprendizado em controle de voo, integração de sensores e captura de imagens.

#### 18.2 Objetivos do Projeto

- Desenvolver um protótipo funcional de drone com controle básico de voo.
- Integrar sensores inerciais e GPS para navegação.
- Capturar imagens com câmera embarcada.
- Estabelecer comunicação com uma estação base para monitoramento.

#### 18.3 Arquitetura de Hardware

Componente Função

STM32 (ex: STM32F4/H7) Microcontrolador principal para controle de voo e sensores

MPU6050 / ICM20948 IMU para estabilização (acelerômetro + giroscópio)

GPS (ex: NEO-6M) Navegação básica

Câmera (ex: OV7670) Captura de imagem para transmissão ou análise

ESCs + Motores Brushless Propulsão

Bateria Li-Po Fonte de energia

Módulo de rádio (NRF24L01 / LoRa) Comunicação com estação base

#### 18.4 Integração de Hardware

###### Fluxo de Conexões:

[Estação Base]

⇅ (Serial / Rádio) [STM32 MCU]

⇅ ⇅ ⇅

[IMU] [GPS] [Câmera OV7670]

⇅

[ESCs + Motores]

#### 18.5 Software e Controle

- Desenvolvimento: C/C++ com STM32CubeIDE ou PlatformIO

###### Controle de Voo:

  - Leitura da IMU para estabilização
  - Algoritmo PID para controle de atitude
  - Leitura de GPS para localização

###### Visão Computacional (opcional):

  - Captura de frames da câmera
  - Transmissão para estação base
  - Processamento externo (ex: em um PC)

#### 18.6 Comunicação

- Interface: UART ou SPI com módulo de rádio
- Protocolo: Simples, para envio de dados de telemetria e imagens
- Estação Base: Aplicativo em Python com PySerial e OpenCV para visualização

#### 18.7 Instalando o STM32 no Arduino IDE

Figura 5 - FK743M2-IIT - STM32H743IIT6

https://community.st.com/t5/stm32-mcus/how-to-program-and-debug-the-stm32-using-the-arduino-ide/ta-p/608514

Adicionar esta String:

https://github.com/stm32duino/BoardManagerFiles/raw/main/package_stmicroelectronics_index.json

#### 18.8 GY-NEO7MV2 – módulo GPS

#### 18.9 Conclusão

Esta versão didática do drone de resgate oferece uma base sólida para aprendizado em sistemas embarcados e robótica aérea. Com foco em simplicidade e baixo custo, ela permite explorar os fundamentos antes de avançar para arquiteturas mais complexas.

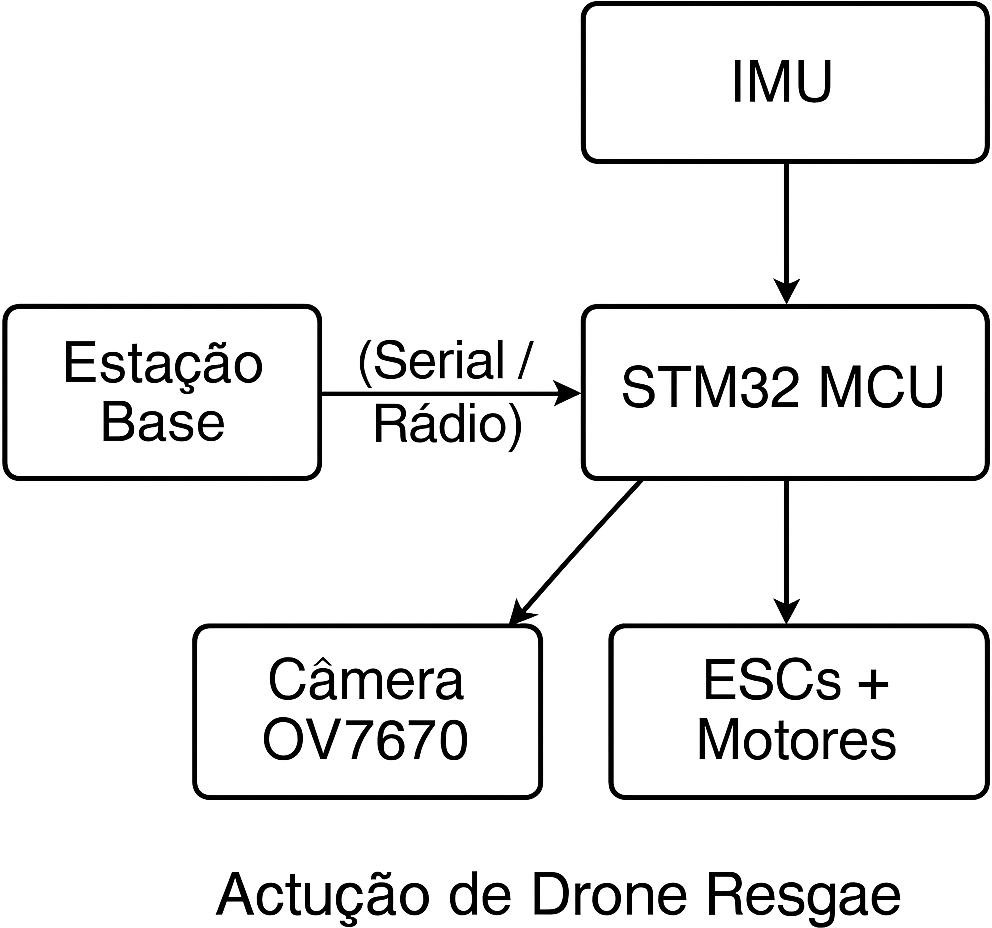
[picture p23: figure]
Diagrama

Dimensionamento do motor de uma asa fixa de 10 kg, siga estes passos: Peso total: W = 10 kg × 9,81 m/s² ≃ 98 N

Razão empuxo/peso (T/W)

- Para cruzeiro leve: 0,3–0,5
- Para decolagem e subida confiável: 0,5–0,7

Ex.: usando T/W = 0,5 → T = 0,5 × 98 ≃ 49 N (≈ 5 kgf)

Estimativa de potência necessária

- P (W) ≃ T (N) × V (m/s) / η_prop
- Supondo V_cruzeiro = 20 m/s e eficiência η_prop ≃ 0,7: P ≃ 49 × 20 / 0,7 ≃ 1 400 W

Folga de 20–30 % → motor que suporte 1 800 W contínuos

tensão e corrente

- Se usar 4 S (14,8 V): I = P/V ≃ 1 800/14,8 ≃ 122 A → ESC de pelo menos 130 A
- Se usar 6 S (22,2 V): I ≃ 1 800/22,2 ≃ 81 A → ESC de 90 A
  1. Defina o KV do motor
    - Quer rotação: RPM ≃ 60×V/(π×D)
    - Ex.: D = 0,35 m → RPM ≃ 60×20/(π×0,35) ≃ 1 100 rpm
    - KV ≃ RPM/V (ex.: em 6 S → KV ≃ 1 100/22,2 ≃ 50 KV)
    - Na prática use KV entre 70 e 150 e ajuste hélice para obter RPM ideal
  2. Verifique empuxo real

Compare curvas de empuxo do fabricante:

Motor + hélice devem gerar ≥ 5 kgf de empuxo a ~70 % de aceleração

  3. Exemplos de motores compatíveis

###### Motor KV Potência cont. Hélice típica Empuxo (4 S)

T-Motor MN4006-14 | 380 KV 1 600 W | 12×6″ | 4,8 kgf
Emax GT3520/08 | 400 KV 1 800 W | 13×6″ | 5,2 kgf
Turnigy Aerodrive SK3-5065-250 250 KV 2 000 W | | 14×7″ | 6,0 kgf

Monte e teste

- Use baterias adequadas (capacidade e C-rate)
- Ajuste hélice e verifique corrente real em solo
- Certifique-se de ter ESC e fiação dimensionados

Com isso você consegue escolher um motor proporcional ao seu projeto de 10 kg. Qualquer dúvida sobre hélices ou bateria, é só falar!

Aqui está um passo-a-passo para dimensionar um motor a combustão para uma asa fixa de 10 kg:

1. Peso da aeronave
  - Massa = 10 kg → Peso ≃ 10 kgf
2. Escolha da razão empuxo/peso (T/W)
  - Para decolagem e subida segura use T/W ≃ 0,5–0,7
  - Empuxo necessário: 0,5 × 22 lbf ≃ 11 lbf
3. Cálculo da potência ao **empuxo** (THP)
  - Use P (HP) = Empuxo (lbf) × Velocidade (mph) / 375
  - Ex.: V cruzeiro ≃ 45 mph → P ≃ 11 × 45 / 375 ≃ 1,32 HP
4. Considere a **eficiência** hélice→empuxo
  - A potência efetiva (THP) costuma ser 25–30 % da BHP do motor
  - Para obter 1,3 HP útil, escolha um motor ≥ 5 HP BHP
5. Margem de segurança
  - Acrescente 20–30 % de folga → busque motor de 1,6 HP THP (~5–6 HP BHP)
6. Exemplos de motores a combustão

| Motor | Cilindrada | BHP (aprox.) | RPM máximo | Peso | Observação |

| OS GT15 (Two Stroke) | 15 cc | ~2,0 HP | 10 000 rpm | 350 g | Popular em aeromodelos|

| DLE 20 (Two Stroke) | 20 cc | ~3,0 HP | 9 000 rpm | 650 g | Boa durabilidade |

| RCGF 30 (Two Stroke) | 30 cc | ~4,0 HP | 8 000 rpm | 900 g | Força extra em subida

7. Integração ao projeto
  - Suporte metálico com antivibração
  - Tanque de 1,5–2 L perto do CG
  - CDI (ignição eletrônica) e servo de corte de combustível
  - Sensor de RPM para telemetria

Com isso, você dimensiona a potência necessária, escolhe um motor que dê a **BHP** adequada e garante empuxo suficiente para levantar-se e manter em voo uma asa fixa de 10 kg.

Vamos aprofundar o dimensionamento de um motor a combustão para uma aeronave de asa fixa com peso máximo de 10 kg, seguindo um fluxo de cálculos detalhado.

###### 1. Definição de parâmetros básicos

  1.1. Peso total (P)
    - Massa = 10 kg
    - Peso em newtons:

P_N = m·g = 10 kg × 9,81 m/s² ≃ 98,1 N

  1.2. Velocidade de cruzeiro (V)
    - Adotaremos V ≃ 20 m/s (≈ 72 km/h), típica para UAVs de asa fixa leves.
  1.3. Razão empuxo/peso (T/W)
    - Para decolagem e subida: T/W ≃ 0,5–0,7
    - Vamos usar T/W = 0,6 como valor de projeto.

→ Empuxo necessário (T_req)

T_req = T/W × P_N = 0,6 × 98,1 N ≃ 58,9 N

###### 2. Cálculo de potência útil (THP)

A potência útil para gerar esse empuxo a V é dada por:

P_thrust = T_req × V

Mas como só parte da potência do motor é convertida em empuxo pela hélice, incluímos a eficiência da hélice η_prop.

  2.1. Sem considerar eficiência: P_ideal = T_req × V = 58,9 N × 20 m/s = 1 178 W
  2.2. Com eficiência de hélice:
    - Hélices típicas têm η_prop ≃ 0,70–0,80 em condições ótimas.
    - Usaremos η_prop = 0,75

P_req = P_ideal / η_prop

= 1 178 W / 0,75

≃ 1 571 W

Isso é a potência no eixo da hélice (em watts).

  2.3. Converter para HP (1 HP = 746 W):

P_req_HP = 1 571 W / 746 ≃ 2,1 HP

###### 3. Do eixo à potência do motor (BHP)

Nem toda a potência do motor chega ao eixo da hélice. Há perdas mecânicas (bomba de óleo, refrigeração, engrenagens, etc.). Adotemos eficiência mecânica η_mech ≃ 0,85.

BHP = P_req_HP / η_mech

= 2,1 HP / 0,85

≃ 2,5 HP

Para segurança e desempenho em variações de altitude/temperatura, recomenda-se levar uma margem extra de ~20 %:

BHP_final ≃ 2,5 HP × 1,2 ≃ 3,0 HP

###### 4. Seleção de cilindrada

Relação empírica em motores 2T:

- 1 HP pode exigir ~10–12 cc de cilindrada.
- Para 3 HP, cilindrada ≃ 30–36 cc.

Em motores 4T, há menor potência específica, então considere ~12–15 cc/HP → 36–45 cc para 3 HP.

###### 5. Exemplos práticos

Motor Tipo Cilindrada BHP nominal Peso (g) Observações

OS GT15 | 2T | 15 cc | 2,0 HP | 350 | Leve, mas talvez subdimensionado
DLE 20 | 2T | 20 cc | 3,0 HP | 650 | Bom equilíbrio potência/peso
RCGF 30 | 2T | 30 cc | 4,0 HP | 900 | Reserva de potência
Saito FA-45 (4T) | 4T | 45 cc | 3,5 HP | 1 200 | Motor 4T, menos vibração

Para nosso projeto (BHP_final ≃ 3,0 HP), DLE 20 (20 cc/3 HP) é um excelente ponto de partida.

###### 6. Verificação de empuxo com hélice

Após escolher o motor, consulte as curvas de empuxo do fabricante para a hélice recomendada (ex: 13×6″ a 9 000 rpm no DLE 20). Verifique:

- Empuxo está ≥ T_req (58,9 N ≃ 6 kgf)
- Potência consumida pela hélice em torno de P_req (1 571 W) Se faltar empuxo, incremente hélice ou cilindrada.

###### 7. Integração ao projeto

1. Suporte do motor reforçado e isolado de vibração
2. Tanque de ~2 L próximo ao CG
3. CDI ou módulo de ignição eletrônica
4. Fonte auxiliar (bateria pequena) para partida elétrica, se houver
5. Sensor de RPM para telemetria no Pixhawk

Com esse detalhamento você tem:

  - Cálculo de empuxo e potência real
  - Conversão para HP e BHP
  - Critérios para escolha de cilindrada
  - Exemplos de motores comerciais

Qualquer ponto que queira explorar mais — por exemplo, curvas de empuxo-helice ou balanceamento de CG — é só dizer!

A seguir um passo-a-passo avançado de dimensionamento de hélice para sua asa-fixa de 10 kg. Vamos calcular:

1. Empuxo necessário em cruzeiro (igual ao arrasto)
2. Empuxo “estático” para decolagem/subida
3. Diâmetro e passo via a equação do empuxo
1. Empuxo em cruzeiro (T_cruise)
  1.1 Parâmetros de voo
    - Peso W = 10 kg → W·g = 98 N
    - Velocidade de cruzeiro V = 20 m/s
    - Densidade do ar ρ = 1,225 kg/m³
  1.2 Área de asa e arrasto
    - Envergadura b = 3,0 m; alongamento AR = 7,5 → S = b²/AR ≃ 1,2 m²
    - Para Cl:

Cl = W/(½·ρ·V²·S) = 98/(0.5·1.225·20²·1.2) ≃ 0,42

    - Arrasto total:

Cdi = Cl²/(π·AR·e) (e≈0,8) → Cdi ≃0,03 Cdo ≃0,03 ⇒ Cd ≃Cdi+Cdo ≃0,06

D = ½·ρ·V²·S·Cd = 0,5·1.225·400·1.2·0.06 ≃ 17,6 N

→ Empuxo em cruzeiro: T_cruise ≃ 17,6 N

2. Empuxo “estático” para decolagem/subida (T_static)
- Para T/W ≃ 0,6 → T_static = 0,6·98 ≃ 59 N

###### 3. Cálculo de diâmetro D e passo P

Usamos a forma empírica:

T = Cₜ·ρ·n²·D⁴ onde

- Cₜ ≃ 0,11 (hélice 2-lâminas, passo médio)
- n = rpm/60 em rps. Ex.: motor a combustão em regime nominal ≃ 9 000 rpm → n=150 rps
  3.1 Diâmetro para cruzeiro (T=17,6 N)
1. D⁴ = T/(Cₜ·ρ·n²) = 17,6/(0.11·1.225·150²) ≃ 0,0063
2. D = 0,0063^(1/4) ≃ 0,31 m → 31 cm ≃ 12″
  3.2 Diâmetro para decolagem (T=59 N)
1. D⁴ = 59/(0.11·1.225·150²) ≃ 0,0194
2. D = 0,0194^(1/4) ≃ 0,37 m → 37 cm ≃ 15″

Compromisso: escolha D≈0,34 m (13″) para atender bem aos dois regimes.

###### 3.3 Cálculo de passo (P)

Desejamos que a hélice “avance” a velocidade de cruzeiro: P = V/n = 20 m/s ÷ 150 rps ≃ 0,133 m → 133 mm ≃ 5,2″

No mercado use P = 5″ ou 6″ (5″ para eficiência em cruzeiro; 6″ para mais empuxo estático).

###### 3.4 Verificação de Mach de ponta

Tip-speed = π·D·n = 3,14·0,34·150 ≃ 160 m/s → Mach ≃ 0,47 OK (<0,7)

Modelo | D × P | Empuxo @80 % throttle | Observação
APC 13×6″ | 0,33×0,15 m | ~6 kgf (≈59 N) | Mais empuxo estático
Graupner 12×5″ | 0,30×0,13 m

###### 4. Hélices comerciais sugeridas

Modelo | D × P | Empuxo @80 % throttle | Observação
APC 13×6″ | 0,33×0,15 m | ~6 kgf (≈59 N) | Mais empuxo estático
Graupner 12×5″ | 0,30×0,13 m | ~4 kgf (≈39 N) | Maior eficiência em cruzeiro
Zinger 14×6″ | 0,36×0,15 m | ~7 kgf (≈69 N) | Incrementa subida

Ajuste final conferindo curvas de empuxo-potência do fabricante e medindo em bancada.

###### 5. Resumo

- Escolha hélice 13×5″ para equilíbrio entre empuxo de decolagem e eficiência em cruzeiro.
- Se precisar de mais empuxo (atalhos, vento forte), vá para 14×6″.
- Sempre valide medindo empuxo estático e potência consumida. Qualquer dúvida sobre ensaio em bancada ou adaptação ao motor, só falar!

Segue um método detalhado para calcular, com maior fidelidade, a autonomia e o empuxo necessários em voo de cruzeiro e subir/colar voos acima de 100 km. Você poderá preencher com

os valores reais do seu modelo (S, AR, pesos, perfil, SFC, rendimentos etc.) e obter números precisos.

###### 1. Defina a missão e os parâmetros de voo

  - Peso vazio + payload: W_empty (N)
  - Combustível inicial: W_fuel_i (N)
  - Peso total inicial: W_i = W_empty + W_fuel_i
  - Peso final (último instante): W_f = W_empty + W_fuel_f (reserve)
  - Velocidade de cruzeiro: V (m/s)
  - Altitude: ρ (kg/m³)
  - Elongamento e área da asa: AR, S (m²)
  - Coeficiente de arrasto zero − lift: C_d0
  - Fator de eficiência induzida: k = 1/(π · AR · e)

###### 2. Calcule o arrasto em cruzeiro

Cl = W_avg/(½ · ρ · V² · S)

C_d = C_d0 + k · Cl²

D = ½ · ρ · V² · S · C_d (N)

###### 3. Potência para manter cruzeiro

P_sℎaft = D · V (W)

P_engine = P_sℎaft/(η_prop · η_mecℎ) (W)

  - η_prop = eficiência da hélice (≈0,75–0,85)
  - η_mech = eficiência mecânica do motor/transmissão (≈0,9)

###### 4. Consumo de combustível

ṁ = c_p · P_engine (kg/s)

  - c_p = SFC em kg de combustível por W·s (ex.: 0,00025 kg/(W·h) → converta para s)

###### 5. Tempo de voo (endurance)

t = (W_fuel_i – W_fuel_f)/ṁ (s)

###### 6. Alcance teórico

R = V · t (m)

7. Breguet (alternativa compacta) Para propulsão a hélice, a fórmula de alcance fica: R = (η_prop·L/D)/c_p × ln(W_i/W_f) (m) onde
  - L/D = razão sustentação/arrasto no cruzeiro
  - ln(W_i/W_f) = logaritmo da fração de peso

###### 8. Exemplo numérico simplificado

  - W_empty = 15 kg → 147 N
  - W_fuel_i = 4 kg → 39 N; W_f = 1 kg → 9,8 N
  - V = 20 m/s; ρ = 1,225 kg/m³; S = 1,5 m²; AR = 12; e = 0,8
  - C_d0 = 0,025 → k = 1/(π·12·0,8)=0,033
  - η_prop = 0,8; η_mech = 0,9; c_p = 0,00027 kg/(W·h)≃7.5e-8 kg/(W·s)
1. Cl ≃ (147+39/2)/(0.5·1.225·400·1,5) ≃ 0,45
2. C_d ≃ 0,025+0,033·0,45² ≃ 0,032
3. D ≃ ½·1.225·400·1,5·0,032 ≃ 11,8 N
4. P_engine ≃ (11,8·20)/(0,8·0,9) ≃ 326 W
5. ṁ ≃ 7.5e-8·326 ≃ 2,4e-5 kg/s → 0,086 kg/h
6. t ≃ (4–1) kg / 0,086 kg/h ≃ 34,9 h
7. R ≃ 20 m/s·34,9·3600 s ≃ 2 512 km

Esse valor exagerado indica que seu avião, bem afinado, pode voar 100 km com folga enorme

- bastaria reduzir o tanque. Ajuste cada parâmetro (S, C_d0, SFC, reservas) para chegar no seu alcance real esperado (por ex. 150–200 km).

Com essas fórmulas você consegue:

  - Otimizar a L/D e C_d0 via perfil e fuselagem;
  - Calcular exatamente o combustível necessário para 100 km + reservas;
  - Escolher hélice e motor que operem no ponto de máxima eficiência.

Se quiser auxílio para montar uma planilha automática ou grafos de sensibilidade (variação de R vs. SFC, L/D, tanques), me avise!

Segue uma **proposta de planilha** em Excel/Google Sheets para dimensionar autonomia e alcance de sua asa-fixa com motor a combustão. Basta criar as colunas conforme abaixo, inserir os valores nas “células de Entrada” e as fórmulas nas “células de Cálculo”:

| | A (Parâmetro) | B (Valor) | C (Unidade) | D (Fórmula em Excel/Sheets)

| A (Parâmetro) | B (Valor) | C (Unidade) | D (Fórmula em Excel/Sheets)
1 | <b>ENTRADAS</b>

2 | Massa vazio | 15 | kg | —
3 | Massa combustível inicial | 4 | kg | —
4 | Massa combustível final (reserva) | 1 | kg | —
5 | Gravidade | 9,81 | m/s² | —
6 | Velocidade cruzeiro | 20 | m/s | —
7 | Densidade do ar (nível do mar) | 1,225 | kg/m³ | —
8 | Área alar (S) | 1,5 | m² | —
9 | Alongamento (AR) | 12 | — | —
10 | Fator Oswald (e) | 0,8 | — | —

| 1 | **ENTRADAS** | | | |

Nº | Parâmetro | Valor | Unidade | Observações
2 | Massa vazio | 15 | kg | —
3 | Massa combustível inicial | 4 | kg | —
4 | Massa combustível final (reserva) | 1 | kg | —
5 | Gravidade | 9,81 | m/s² | —
6 | Velocidade cruzeiro | 20 | m/s | —
7 | Densidade do ar (nível do mar) | 1,225 | kg/m³ | —
8 | Área alar (S) | 1,5 | m² | —
9 | Alongamento (AR) | 12 | — | —
10 | Fator Oswald (e) | 0,8 | — | —

| 2 | Massa vazio | 15 | kg | — |

| 3 | Massa combustível inicial | 4 | kg | — |

| 4 | Massa combustível final (reserva)| 1 | kg | — |

| 5 | Gravidade | 9,81 | m/s² | — |

| 6 | Velocidade cruzeiro | 20 | m/s | — |

| 7 | Densidade do ar (nível do mar) | 1,225 | kg/m³ | — |

| 8 | Área alar (S) | 1,5 | m² | — |

| 9 | Alongamento (AR) | | 12 | | — | | | —
|10 | Fator Oswald (e) | | 0,8 | | — | | | —
|11 | Cd0 (arrasto parasita) | | 0,025 | | — | | | —
|12 | Eficiência hélice (η_prop) | | 0,80 | | — | | | —
|13 | Eficiência mecânica (η_mech) | 0,90 | | | | — | | —

# Tabela de Dados Técnicos

Nº | Parâmetro | Valor | Unidade | Observações
2 | Massa vazio | 15 | kg | —
3 | Massa combustível inicial | 4 | kg | —
4 | Massa combustível final (reserva) | 1 | kg | —
5 | Gravidade | 9,81 | m/s² | —
6 | Velocidade cruzeiro | 20 | m/s | —
7 | Densidade do ar (nível do mar) | 1,225 | kg/m³ | —
8 | Área alar (S) | 1,5 | m² | —
9 | Alongamento (AR) | 12 | — | —
10 | Fator Oswald (e) | 0,8 | — | —

ID | Parameter | Value | Unit | Notes
14 | SFC (c_p) | 7,5E-8 | kg/(W·s) | use kg/(W·s), ex. 0.00027 kg/(W·h)→7,5E-8
15 | PESOS [N]
16 | W_empty (N) | | N | =B2*B5
17 | W_fuel_i (N) | | N | =B3*B5
18 | W_fuel_f (N) | | N | =B4*B5
19 | W_i (N) | | N | =B16+B17
20 | W_f (N) | | N | =B16+B18

Linha | Descrição | Unidade | Fórmula
21 | CÁLCULOS AERODINÂMICOS

22 | Cl_cruise | | =B19/(0.5*B7*B6^2*B8)
23 | k_ind | | =1/(PI()*B9*B10)
24 | Cd_total | | =B11 + B23*B22^2
25 | Arrasto D (N) | N | =0.5*B7*B6^2*B8*B24
26 | P_shaft (W) | W | =B25*B6
27 | P_engine (W) | W | =B26/(B12*B13)

|28| Vazão combustível ṁ (kg/s) | | kg/s | =B14*B27 |

|29| Endurance (s) | | | | s | | | | =(B17-B18)/B28
|30| Endurance (h) | | | | h | | | | =B29/3600
|31| Alcance (m) | | | | m | | | | =B6*B29
|32| Alcance (km) | | | | km | | | | =B31/1000
|33| **BREGUET (alternativa)**
|34| L/D_cruise | | | | | | — | | =B22/B24
|35| Alcance_Breguet (m) | | | | | | | | m | | | | =(B12*B34)/B14*LN(B19/B20)
|36| Alcance_Breguet (km) | | | | | km | | | | | =B35/1000

Vazão combu stível ṁ | Endur ance (s) | Endur ance (h) | Alca nce (m) | Alca nce (km) | BREGU ET (altern ativa) | L/D_cr uise | Alcance_B reguet (m) | Alcance_B reguet (km)
kg/s | s | h | m | km | | — | m | km

Passos para usar:

1. Crie uma planilha com as colunas A–D.
2. Preencha B2–B14 com seus dados de projeto.
3. Copie as fórmulas de D16–D36 nas células correspondentes da coluna B.
4. Ajuste referências absolutas ($) conforme seu estilo.
5. Verifique os resultados em B29, B32 e/ou B36.

Com isso você terá um cálculo dinâmico de consumo, autonomia e alcance (via arrasto direto e via Breguet), bastando alterar qualquer entrada. Se quiser incluir curvas de sensibilidade (tabela de dados + gráfico) ou automatizar cenários, me avise!

As planilhas que mencionei anteriormente foram criadas sob medida para você, com base nos princípios de engenharia de voo e desempenho de aeronaves. Mas se você está se referindo a planilhas já existentes em escolinhas de aeromodelismo, há sim alguns recursos interessantes disponíveis online. Aqui estão alguns exemplos:

ç# ¡/ Planilhas e Recursos Didáticos de Aeromodelismo

###### 1. Planilha de Cálculo de Aeromodelos – Escolinha de Aeromodelismo

Uma planilha clássica que ajuda a estimar dimensões, área alar, carga alar e empuxo necessário para modelos básicos.

³ Ver planilha no blog Escolinha de Aeromodelismo (https://aeroescolinha.blogspot.com/2011/01/planilha-de-calculo-de-aeromodelos.html)

###### 2. Kit com 2000 plantas de aeromodelos (PDF e vetores)

Inclui plantas para corte, montagem e até arquivos para impressão 3D.

³ Ver kit no Maggero.com (https://maggero.com/producto/2000-planos-para-aeromodelismo-y-radiocontrol/)

###### 3. Plantas para aeromodelos – ToyWing

Oferece arquivos PDF para impressão em escala real, com instruções para montagem e sugestões de perfis.

³ Acessar biblioteca ToyWing (https://toywing.com.br/planta-de-aeromodelo/)

###### 4. Fábrica do Projeto – Arquivos e planilhas técnicas

Repositório com desenhos CAD, planilhas de cálculo e ferramentas para engenharia aplicada ao aeromodelismo.

³ Ver acervo da Fábrica do Projeto (https://www.fabricadoprojeto.com.br/tag/aeromodelos/)

5. **Aula de Aeromodelismo – Mega biblioteca de plantas

## H_] **1. Planilha da Escolinha de Aeromodelismo**

Uma planilha clássica e didática que calcula área alar, carga alar, empuxo necessário e dimensões básicas.

³ [Acessar planilha no blog Escolinha de Aeromodelismo](https://aeroescolinha.blogspot.com/2011/01/planilha-de-calculo-de-aeromodelos.html)

### H_] **2. Planilha de Cálculo de Aeromodelos – Studylib**

Inclui fórmulas para sustentação, arrasto, potência e escolha de hélice. Muito útil para modelos com motor a combustão.

³ [Ver planilha em PDF no Studylib](https://studylib.es/doc/785678/cálculo-fácil-y-rápido-de-aeromodelos)

### H_] **3. Planilha Técnica – Scribd**

Documento completo com fórmulas para Cl, Cd, empuxo, potência e dimensionamento de asas e empenagens.

³ [Acessar PDF no Scribd](https://es.scribd.com/document/133883530/Calculo-De-Aeromodelos)

### k ´˙×. **4. Artigo técnico com planilhas e simulações – ABCM**

Apresenta cálculos estruturais de asa, trem de pouso, motor e hélice com base em projeto real da SAE Brasil.

³ [Ler artigo completo (PDF)](https://www.abcm.org.br/anais/conem/2010/PDF/CON10-2150.pdf)

---m(t) = m_{\text{estrutura}} + \frac{E(t)}{e_{\text{bat}}}

### \‘z’ **5. Biblioteca de desenhos e planilhas – Fábrica do Projeto**

Mais de 100 arquivos com plantas, cortes e planilhas para construção e análise de desempenho.

³ [Explorar acervo técnico](https://www.fabricadoprojeto.com.br/2022/04/desenhos-para-fabricacao-de-aeromodelos/)

Se quiser, posso adaptar uma dessas planilhas para o seu projeto específico (motor a combustão, 10 kg, 100+ km de alcance) e te enviar o modelo pronto para preencher. Deseja isso?

\begin{align}

E(t)\ &=\ m_{\text{bat}}\ \cdot\ e_{\text{bat}}\ \\

P(t)\ &=\ \frac{a}{\eta}\ \left(\ m_{\text{estrutura}}\ +\ \frac{E(t)}{e_{\text{bat}}}\ \right)^2\ \\

\frac{dE}{dt}\ &=\ -P(t)

\end{align}

\begin{align}

E(t)\ &=\ m_{\text{bat}}\ \cdot\ e_{\text{bat}}\ \\

P(t)\ &=\ \frac{a}{\eta}\ \left(\ m_{\text{estrutura}}\ +\ \frac{E(t)}{e_{\text{bat}}}\ \right)^2\ \\

\frac{dE}{dt}\ &=\ -P(t)

〗{align

}

CL = \frac {2, (m{\text{estrutura}} + m{\text{bat}}), g} {ρ, V2,S}

C_L = \frac{2\,(m_{\text{estrutura}}+m_{\text{bat}})\,g}{\rho\,V^2\,S}

C_D = C_{D0} + k\, C_L^2

Título: Dimensionamento de Autonomia de Asa Fixa Elétrica Autor: Nilberto

Data:

1. Introdução

Este documento apresenta o modelo matemático e as equações em LaTeX para calcular a autonomia de voo de uma aeronave de asa fixa movida a motor elétrico, considerando o efeito do peso da bateria no consumo de energia.

2. Parâmetros de projeto
  - Massa da estrutura: m_{\text{estrutura}}=10\ \mathrm{kg}
  - Densidade energética da bateria: e_{\text{bat}}=200\ \mathrm{Wh/kg}
  - Eficiência total (motor+hélice): \eta=0{,}75
  - Velocidade de cruzeiro: V=20\ \mathrm{m/s}
  - Área alar: S=1{,}5\ \mathrm{m^2}
  - Densidade do ar: \rho=1{,}225\ \mathrm{kg/m^3}
  - Coef. de arrasto parasita: C_{D0}=0{,}03
  - Fator de eficiência induzida: k=\frac{1}{\pi\cdot AR\cdot e}
3. Equações principais

(cole cada bloco e pressione Alt + = para converter em equação) C_L = \frac{2\,(m_{\text{estrutura}}+m_{\text{bat}})\,g}{\rho\,V^2\,S}

C_D\ =\ C_{D0}\ +\ k\, C_L^2\

D\ =\ \frac12\,\rℎo\, V^2\, S\, C_D\

P_{\text{sℎaft}}\ =\ D\, V\

P_{\text{eletrica}}\ =\ \frac{P_{\text{sℎaft}}}{\eta}\

E_{\text{bat}}\ =\ m_{\text{bat}}\; e_{\text{bat}}\

\frac{dE}{dt}\

=\ −P_{\text{eletrica}}\ \quad\Longrigℎtarrow\quad\ \frac{dE}{dt}

\

=\ −\frac{a}{\eta}\Bigl(m_{\text{estrutura}}\ +\ \frac{E}{e_{

\text{bat}}}\Bigr)^2\

1. Otimização de m_{\text{bat}}

t(m_{\text{bat}}) = \frac{E_{\text{bat}}}{P_{\text{eletrica}}}

= \frac{m_{\text{bat}}\, e_{\text{bat}}\,\eta}{a\, (m_{

\text{estrutura}} + m_{\text{bat}})^2}

dt

dmbat

= 0 ⇒ bat = mestrutura

2. Gráfico de t vs. m_{\text{bat}}

Após renderizar as equações, insira um gráfico de Dispersão (Inserir → Gráfico → Dispersão com linhas suaves) usando uma tabela de valores m_{\text{bat}}=1…15 e t(m_{\text{bat}}) calculado em Excel ou num mini-cálculo dentro do Word.

Título: Dimensionamento de Autonomia de Asa Fixa Elétrica Autor: Nilberto

Data:

1. Introdução

Este documento apresenta o modelo matemático e as equações em LaTeX para calcular a autonomia de voo de uma aeronave de asa fixa movida a motor elétrico, considerando o efeito do peso da bateria no consumo de energia.

2. Parâmetros de projeto
  - Massa da estrutura: mestrutura = 10 kg
  - Densidade energética da bateria: ebat = 200 Wh/kg
  - Eficiência total (motor+hélice): η = 0,75
  - Velocidade de cruzeiro: V = 20 m/s
  - Área alar: S = 1,5 m²
  - Densidade do ar: ρ = 1,225 kg/m³
  - Coef. de arrasto parasita: CD0 = 0,03
  - Fator de eficiência induzida: k = 1

π⋅AR⋅e

3. Equações principais

CL =

2 (mestrutura + mbat) g ρ V² S

CD = CD0 + k C²

L

D = 1 ρ V² S C

2 D

Pshaft = D V

Peletrica =

Pshaft η

Ebat = mbat ebat

dE

dE a

E 2

dt = −Peletrica ⟹ dt = − η (mestrutura + e )

bat

1. Otimização de mbat

t(m

) = Ebat = mbat ebat η

1. Gráfico de t vs. mbat:

bat

Peletrica

dt

dmbat

a (mestrutura + mbat)2

= 0 ⇒ mbat = mestrutura

Após renderizar as equações, insira um gráfico de Dispersão (Inserir → Gráfico → Dispersão com linhas suaves) usando uma tabela de valores mbat = 1 … 15 e t(m_{"{bat}} calculado em Excel ou num mini-cálculo dentro do Word.

Para motor a combustão:

Título: Dimensionamento de Autonomia – Asa Fixa com Motor a Combustão Autor: Nilberto

Data:

1. Introdução

Este documento apresenta o modelo matemático em LaTeX para calcular autonomia e consumo de combustível de uma aeronave de asa fixa com motor a combustão.
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

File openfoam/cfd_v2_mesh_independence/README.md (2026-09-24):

# CFD v2 — independência de malha em cruzeiro

Este estudo preserva integralmente os casos legados em `openfoam/cruise_25ms_*` e
cria uma campanha independente para o ponto de referência de cruzeiro:

- velocidade: 25 m/s;
- ângulo de ataque: +4 graus;
- escoamento incompressível RANS;
- turbulência: `kOmegaSST`;
- `Aref = 2.604 m2`, `lRef = 0.6415 m`, `CofR = (1.07 0 0)`;
- geometria: cópia verificada do STL usado na campanha original;
- estratégia de parede: baixo Reynolds, alvo `y+` próximo de 1.

## Organização

```text
cfd_v2_mesh_independence/
├── geometry/                 STL comum e checksum
├── common/                   campos e dicionários compartilhados
├── cases/
│   ├── coarse/               alvo aproximado: 0.3 M células
│   ├── medium/               alvo aproximado: 1–2 M células
│   └── fine/                 alvo aproximado: 4–6 M células
├── scripts/extract_results.py
├── results/                  tabelas geradas pelo pós-processamento
├── Allmesh
└── Allrun
```

Cada caso possui seus próprios `blockMeshDict`, `snappyHexMeshDict`, malha,
resultados e logs. Nenhum script escreve nos casos anteriores.

Após o `snappyHexMesh`, `Allmesh` registra a última tabela de camadas em
`log.layerSummary`. Se nenhuma camada sobreviver aos controles de qualidade, cria
`NO_PRISM_LAYERS`; nesse estado `Allrun` bloqueia a solução para impedir que uma
malha sem a física pretendida seja confundida com CFD v2 válido. A variável
`ALLOW_NO_LAYERS=1` existe somente para testes diagnósticos explícitos.
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

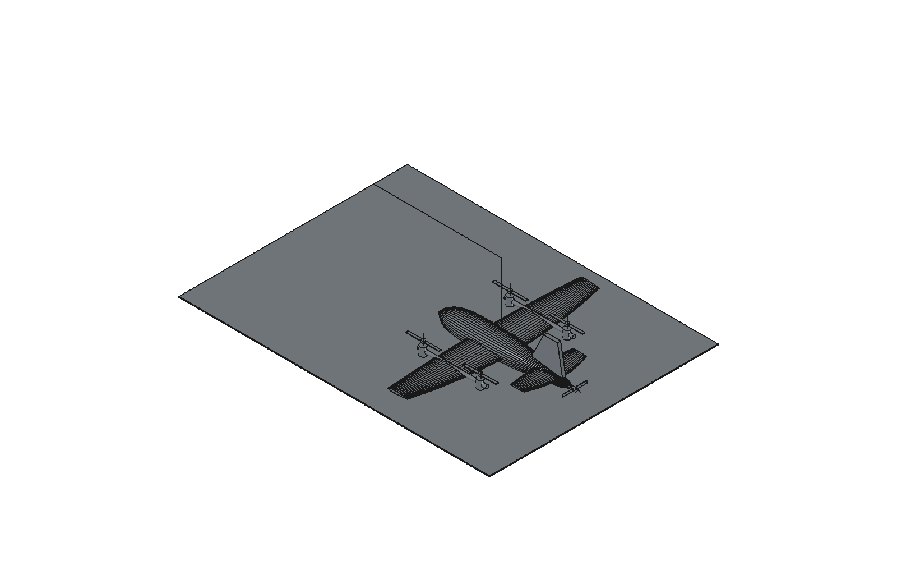
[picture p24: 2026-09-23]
uav_cargo_animation_preview.png

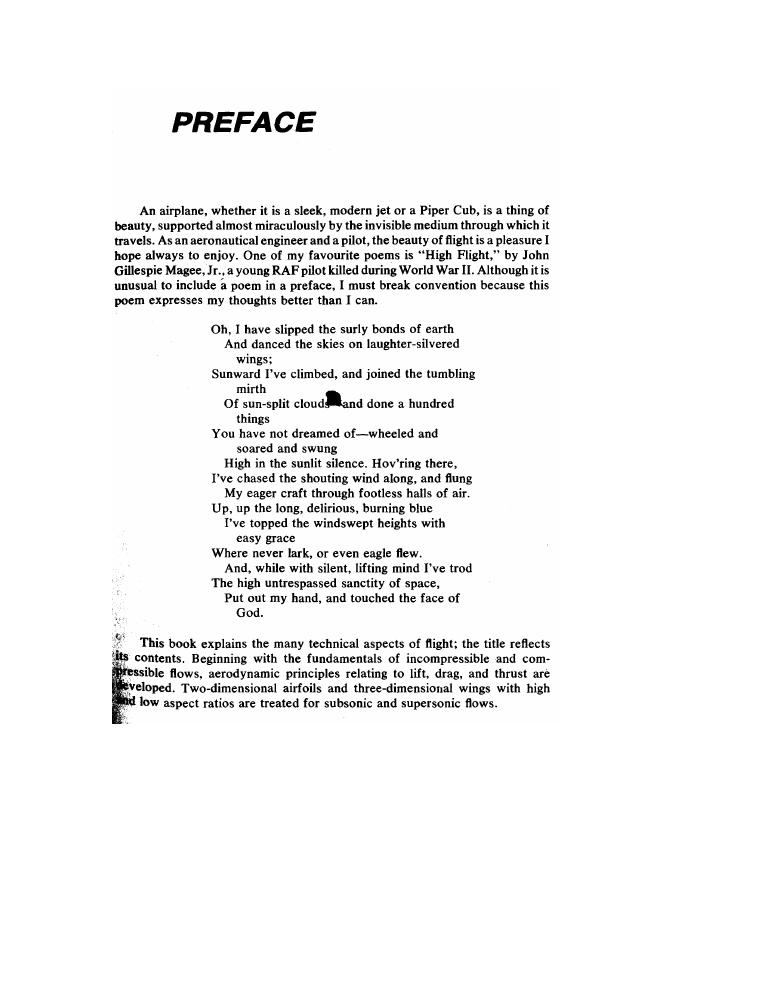
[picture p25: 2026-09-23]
tmp/pdfs/mccormick/page-004.jpg

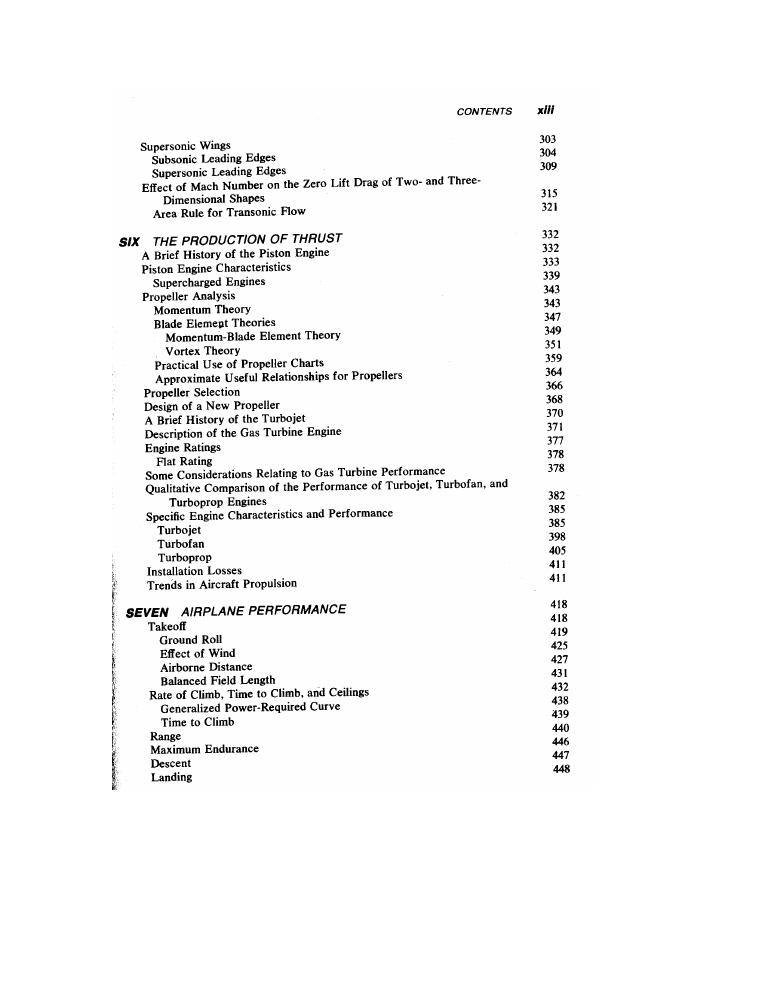
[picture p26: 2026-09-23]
tmp/pdfs/mccormick/page-009.jpg

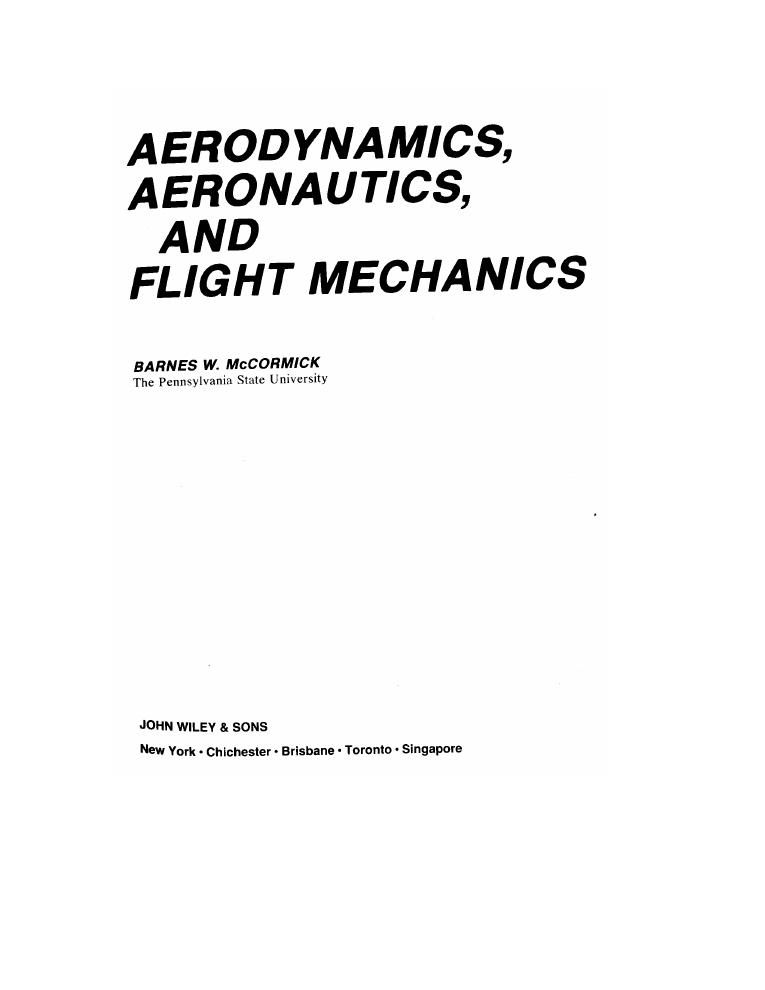
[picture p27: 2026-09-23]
tmp/pdfs/mccormick/page-002.jpg

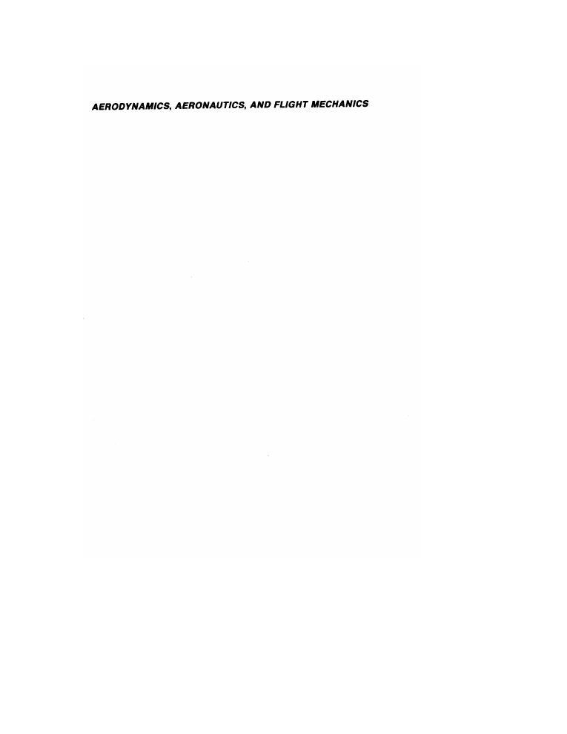
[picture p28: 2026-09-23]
tmp/pdfs/mccormick/page-013.jpg

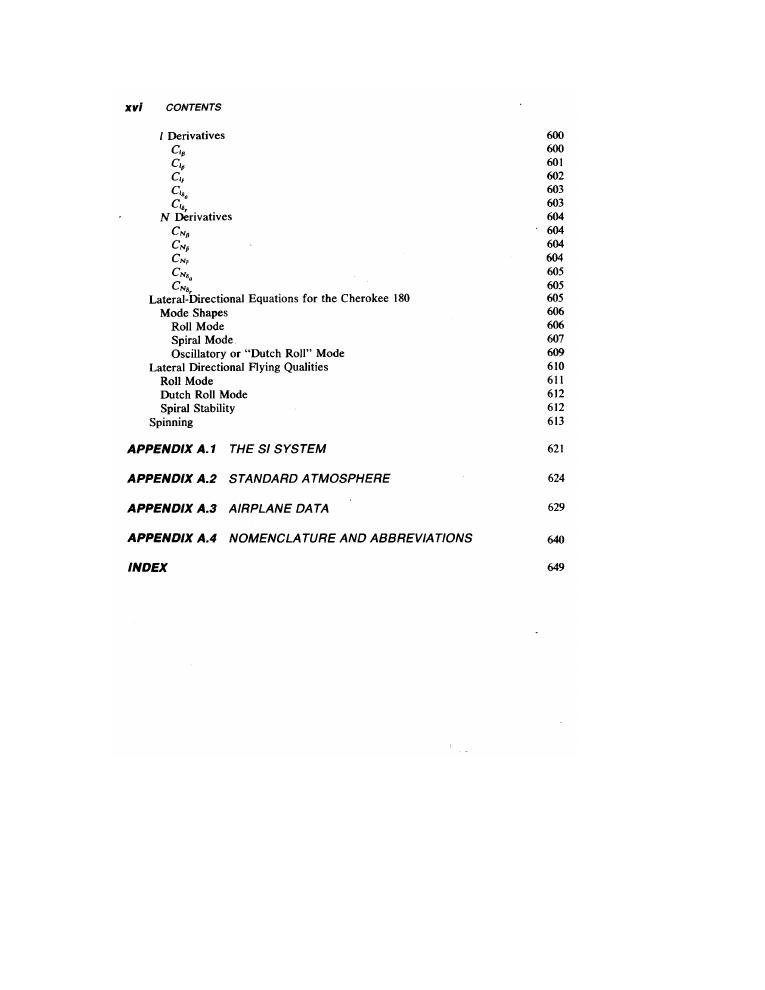
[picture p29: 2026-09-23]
tmp/pdfs/mccormick/page-012.jpg

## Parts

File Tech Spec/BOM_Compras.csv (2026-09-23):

ID | Categoria | Item | Quantidade | Maturidade | Candidato/modelo | Arquivo Data sheet
DS-001 | Aviónica | Controlador de voo | 1 | Arquitetura aceita | Holybro Pixhawk 6X | Data sheets/DS-001_controlador_de_voo.md
DS-002 | Aviónica | Computador de missão | 1 | Arquitetura aceita | Raspberry Pi 5 — 8 GB | Data sheets/DS-002_computador_de_missao.md
DS-003 | Aviónica | Refrigerador do computador | 1 | Candidato | Raspberry Pi Active Cooler | Data sheets/DS-003_refrigerador_do_computador.md
DS-004 | Aviónica | Módulo GNSS/RTK + magnetômetro | 1 | Candidato | Holybro H-RTK NEO-F9P + RM3100 | Data sheets/DS-004_modulo_gnss_rtk_magnet_metro.md
DS-005 | Aviónica | Sensor de velocidade do ar + pitot | 1 | Candidato | Holybro MS5525 | Data sheets/DS-005_sensor_de_velocidade_do_ar_pitot.md
DS-006 | Aviónica | Altímetro laser | 1 | Candidato | LightWare SF11/C | Data sheets/DS-006_altimetro_laser.md
DS-007 | Missão | Câmera RGB | 1 | Candidato | Raspberry Pi Camera Module 3 Wide | Data sheets/DS-007_c_mera_rgb.md
DS-008 | Missão | Câmera térmica | 1 | Opcional / candidato | Teledyne FLIR Boson 320 ou 640 | Data sheets/DS-008_c_mera_termica.md
DS-009 | Aviónica | Armazenamento de missão | 2 | TBD | microSD High Endurance ou NVMe industrial | Data sheets/DS-009_armazenamento_de_missao.md
DS-010 | Aviónica | Buzzer e localizador | 1 | TBD | Buzzer ativo + beacon independente | Data sheets/DS-010_buzzer_e_localizador.md
DS-011 | Aviónica | Módulo de relógio RTC | 1 | TBD | RTC industrial com bateria/supercapacitor | Data sheets/DS-011_modulo_de_relogio_rtc.md
DS-012 | Comunicação | Rádio telemetria de bordo | 1 | Candidato | RFD900x-BR | Data sheets/DS-012_radio_telemetria_de_bordo.md
DS-013 | Comunicação | Rádio telemetria de solo | 1 | Candidato | RFD900x-BR USB | Data sheets/DS-013_radio_telemetria_de_solo.md
DS-014 | Comunicação | Conjunto de antenas e cabos RF | 1 kit | TBD | Antenas 900 MHz + cabos coaxiais | Data sheets/DS-014_conjunto_de_antenas_e_cabos_rf.md
DS-015 | Comunicação | Modem 4G | 1 | Candidato | Waveshare SIM7600G-H 4G HAT | Data sheets/DS-015_modem_4g.md
DS-016 | Comunicação | Antenas LTE/GNSS do modem | 1 kit | TBD | Antenas compatíveis com SIM7600 | Data sheets/DS-016_antenas_lte_gnss_do_modem.md
DS-017 | Propulsão VTOL | Motor elétrico de sustentação | 4 | Candidato — compra bloqueada | T-Motor U10 II KV100 | Data sheets/DS-017_motor_eletrico_de_sustentacao.md
DS-018 | Propulsão VTOL | ESC dos motores de sustentação | 4 | Candidato — compra bloqueada | T-Motor ALPHA 80A 12S | Data sheets/DS-018_esc_dos_motores_de_sustentacao.md
DS-019 | Propulsão VTOL | Hélice VTOL CW 30×10,5 | 2 + 1 reserva | Candidato — compra bloqueada | T-Motor G30×10.5 CW | Data sheets/DS-019_helice_vtol_cw_30_10_5.md
DS-020 | Propulsão VTOL | Hélice VTOL CCW 30×10,5 | 2 + 1 reserva | Candidato — compra bloqueada | T-Motor G30×10.5 CCW | Data sheets/DS-020_helice_vtol_ccw_30_10_5.md
DS-021 | Tilt-rotor | Atuador de inclinação da nacele | 4 | TBD crítico | Atuador eletromecânico industrial com feedback absoluto | Data sheets/DS-021_atuador_de_inclinacao_da_nacele.md
DS-022 | Tilt-rotor | Trava mecânica da nacele | 4 | TBD crítico | Pino/trava fail-safe com sensor duplo | Data sheets/DS-022_trava_mec_nica_da_nacele.md
DS-023 | Tilt-rotor | Sensor de indexação/parada da hélice | 4 | TBD crítico | Encoder/Hall redundante | Data sheets/DS-023_sensor_de_indexacao_parada_da_helice.md
DS-024 | Tilt-rotor | Mancais e eixo do pivô | 4 kits | TBD crítico | Rolamentos selados + eixo 7075/aço | Data sheets/DS-024_mancais_e_eixo_do_piv.md
DS-025 | Propulsão cruzeiro | Motor a gasolina pusher | 1 | Candidato — compra bloqueada | DLE35RA | Data sheets/DS-025_motor_a_gasolina_pusher.md
DS-026 | Propulsão cruzeiro | Hélice pusher | 2 | TBD crítico | 19×8 ou 20×8 pusher compatível | Data sheets/DS-026_helice_pusher.md
DS-027 | Propulsão cruzeiro | Servo de aceleração | 1 | TBD | Servo HV metal gear | Data sheets/DS-027_servo_de_aceleracao.md
DS-028 | Propulsão cruzeiro | Módulo de corte da ignição | 1 | TBD crítico | Kill switch optoisolado | Data sheets/DS-028_modulo_de_corte_da_ignicao.md
DS-029 | Propulsão cruzeiro | Sensor de RPM do motor térmico | 1 | TBD | Sensor Hall/óptico isolado | Data sheets/DS-029_sensor_de_rpm_do_motor_termico.md
DS-030 | Propulsão cruzeiro | Motor elétrico starter-generator | 1 | TBD crítico | BLDC dimensionado para partida e geração | Data sheets/DS-030_motor_eletrico_starter_generator.md
DS-031 | Propulsão cruzeiro | Controlador bidirecional starter-generator | 1 | TBD crítico | Inversor/retificador BLDC bidirecional | Data sheets/DS-031_controlador_bidirecional_starter_generator.md
DS-032 | Propulsão cruzeiro | Embreagem/roda livre e transmissão | 1 kit | TBD crítico | Roda livre + correia/engrenagem | Data sheets/DS-032_embreagem_roda_livre_e_transmissao.md
DS-033 | Combustível | Tanque ou bladder de combustível | 1 | TBD crítico | Capacidade geométrica inicial 4 L | Data sheets/DS-033_tanque_ou_bladder_de_combustivel.md
DS-034 | Combustível | Kit de linhas, filtro, clunk e respiro | 1 kit | TBD | Componentes compatíveis com gasolina | Data sheets/DS-034_kit_de_linhas_filtro_clunk_e_respiro.md
DS-035 | Combustível | Válvula de corte de combustível | 1 | TBD crítico | Válvula fail-safe compatível com gasolina | Data sheets/DS-035_valvula_de_corte_de_combustivel.md
DS-036 | Combustível | Sensor de nível/fluxo de combustível | 1 | TBD | Sensor compatível com gasolina | Data sheets/DS-036_sensor_de_nivel_fluxo_de_combustivel.md
DS-037 | Energia | Célula Li-ion 21700 | 48 | Candidato — compra bloqueada | Molicel INR-21700-P45B; pack conceitual 12S4P | Data sheets/DS-037_celula_li_ion_21700.md
DS-038 | Energia | BMS/monitor de células 12S | 1 | TBD crítico | BMS aeronáutico ou monitor independente | Data sheets/DS-038_bms_monitor_de_celulas_12s.md
DS-039 | Energia | Contator principal HV | 1 | TBD crítico | Contator DC ≥60 V | Data sheets/DS-039_contator_principal_hv.md
DS-040 | Energia | Circuito de pré-carga | 1 | TBD crítico | Resistor + relé/contator de pré-carga | Data sheets/DS-040_circuito_de_pre_carga.md
DS-041 | Energia | Fusível principal HV | 1 + 2 reservas | TBD crítico | Fusível DC aeronáutico/EV | Data sheets/DS-041_fusivel_principal_hv.md
DS-042 | Energia | Distribuidor/barramento de potência HV | 1 | Sob medida | PDB/busbar 12S | Data sheets/DS-042_distribuidor_barramento_de_pot_ncia_hv.md
DS-043 | Energia | Módulo de medição de potência | 1 | Candidato | Holybro PM08-CAN ou solução equivalente | Data sheets/DS-043_modulo_de_medicao_de_pot_ncia.md
DS-044 | Energia | Conversor DC/DC 5 V 5 A isolado | 2 | TBD crítico | Conversores industriais redundantes | Data sheets/DS-044_conversor_dc_dc_5_v_5_a_isolado.md
DS-045 | Energia | Conversor DC/DC 12 V | 1 | TBD | Conversor industrial 12S→12 V | Data sheets/DS-045_conversor_dc_dc_12_v.md
DS-046 | Energia | Bateria reserva de aviónica | 1 | TBD crítico | Pack LiFePO4 independente | Data sheets/DS-046_bateria_reserva_de_avionica.md
DS-047 | Energia | Módulo ideal-diode/OR-ing | 1 | TBD crítico | OR-ing de duas fontes | Data sheets/DS-047_modulo_ideal_diode_or_ing.md
DS-048 | Energia | Conectores antifaísca HV | 1 kit | TBD | AS150 ou equivalente qualificado | Data sheets/DS-048_conectores_antifaisca_hv.md
DS-049 | Energia | Cabos de potência e sinal | 1 lote | TBD | Cabos flexíveis aeronáuticos | Data sheets/DS-049_cabos_de_pot_ncia_e_sinal.md
DS-050 | Energia | Sensores de temperatura | 8 | TBD | NTC/PT1000 digitais/analógicos | Data sheets/DS-050_sensores_de_temperatura.md
DS-051 | Controles | Servo de aileron HV | 2 + 1 reserva | TBD crítico | Servo digital industrial metal gear | Data sheets/DS-051_servo_de_aileron_hv.md
DS-052 | Controles | Servo de ruddervator da cauda V | 2 + 1 reserva | TBD crítico | Servo digital industrial metal gear | Data sheets/DS-052_servo_de_ruddervator_da_cauda_v.md
DS-053 | Controles | Servo de porta/liberação de carga | 1 | TBD | Servo ou atuador com trava | Data sheets/DS-053_servo_de_porta_liberacao_de_carga.md
DS-054 | Controles | Hinges, horns e pushrods | 1 kit | TBD | Ferragens aeronáuticas | Data sheets/DS-054_hinges_horns_e_pushrods.md
DS-055 | Estrutura | Longarinas/tubos de fibra de carbono | 1 lote | TBD crítico | Tubos/pultrudados com certificado | Data sheets/DS-055_longarinas_tubos_de_fibra_de_carbono.md
DS-056 | Estrutura | Tecido de carbono e epóxi | 1 lote | TBD | Sistema laminado aeronáutico | Data sheets/DS-056_tecido_de_carbono_e_epoxi.md
DS-057 | Estrutura | Núcleo de espuma/honeycomb | 1 lote | TBD | PVC estrutural ou honeycomb | Data sheets/DS-057_nucleo_de_espuma_honeycomb.md
DS-058 | Estrutura | Compensado aeronáutico/firewall | 1 lote | TBD crítico | Compensado birch aeronáutico | Data sheets/DS-058_compensado_aeronautico_firewall.md
DS-059 | Estrutura | Perfis/chapas de alumínio 7075-T6 | 1 lote | TBD crítico | Material com certificado | Data sheets/DS-059_perfis_chapas_de_aluminio_7075_t6.md
DS-060 | Estrutura | Fixadores e porcas travantes | 1 lote | TBD | Classe aeronáutica, tamanhos por desenho | Data sheets/DS-060_fixadores_e_porcas_travantes.md
DS-061 | Estrutura | Coxins antivibração | 1 kit | TBD | Isoladores motor/aviónica | Data sheets/DS-061_coxins_antivibracao.md
DS-062 | Estrutura | Trem de pouso/skids | 1 conjunto | TBD crítico | Compósito/alumínio absorvente | Data sheets/DS-062_trem_de_pouso_skids.md
DS-063 | Estrutura | Proteção térmica e corta-fogo | 1 kit | TBD crítico | Manta/barreira compatível com gasolina | Data sheets/DS-063_protecao_termica_e_corta_fogo.md
DS-064 | Segurança | Sistema de paraquedas | 1 | TBD crítico | Fruity Chutes ou equivalente dimensionado pelo MTOW | Data sheets/DS-064_sistema_de_paraquedas.md
DS-065 | Segurança | Controlador de terminação/recuperação | 1 | TBD crítico | Controlador independente | Data sheets/DS-065_controlador_de_terminacao_recuperacao.md
DS-066 | Segurança | Luzes de navegação e anticolisão | 1 kit | TBD | LEDs aeronáuticos de alta intensidade | Data sheets/DS-066_luzes_de_navegacao_e_anticolisao.md
DS-067 | Solo | Carregador/balanceador 12S | 1 | TBD crítico | Carregador CC/CV com logging | Data sheets/DS-067_carregador_balanceador_12s.md
DS-068 | Solo | Gabinete de armazenamento de baterias | 1 | TBD crítico | Armário resistente ao fogo ventilado | Data sheets/DS-068_gabinete_de_armazenamento_de_baterias.md
DS-069 | Solo | Bancada de empuxo e célula de carga | 1 | TBD crítico | Bancada ≥15 kgf por motor | Data sheets/DS-069_bancada_de_empuxo_e_celula_de_carga.md
DS-070 | Solo | Tacômetro e instrumentos elétricos | 1 kit | TBD | Tacômetro óptico + analisador DC | Data sheets/DS-070_tac_metro_e_instrumentos_eletricos.md
DS-071 | Solo | Estação de controle em solo | 1 | TBD | Notebook robusto com Mission Planner/QGroundControl | Data sheets/DS-071_estacao_de_controle_em_solo.md

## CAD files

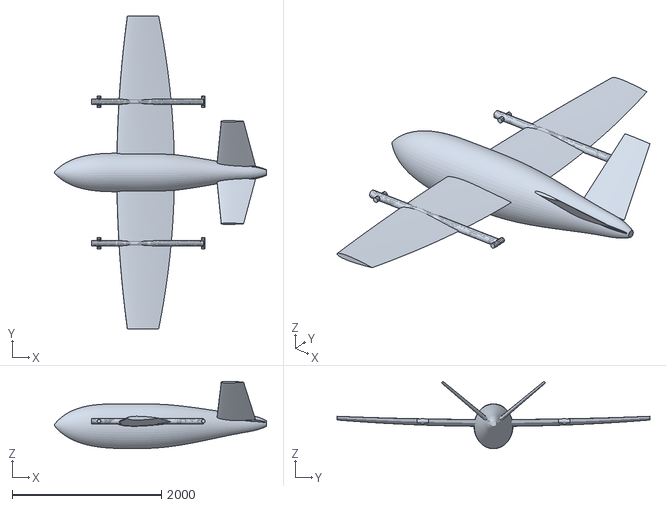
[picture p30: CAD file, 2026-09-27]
uav_cargo_manufacturable/Aircraft rigid-body assembly (Meshed).stl
2850.0 x 4200.0 x 905.0

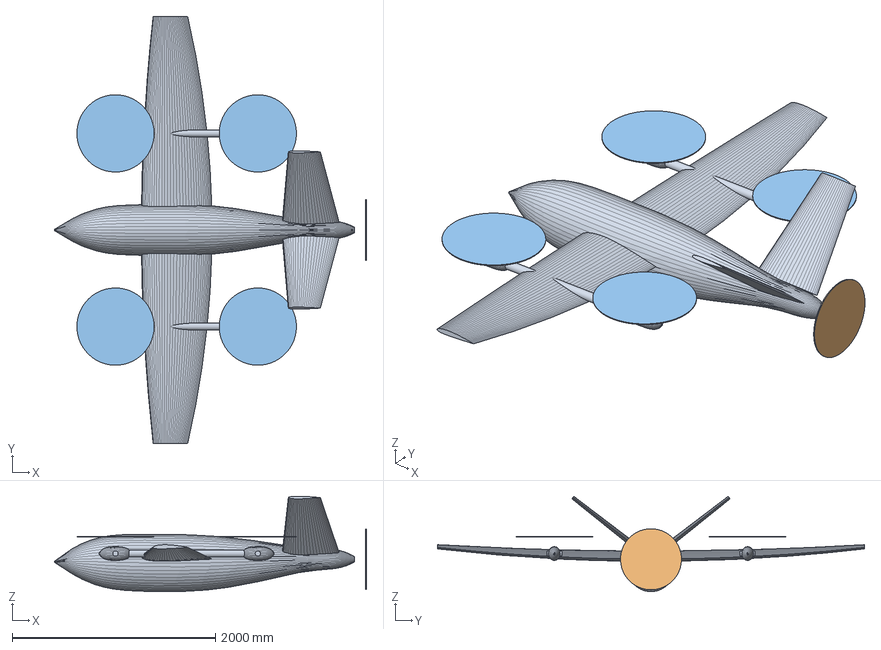
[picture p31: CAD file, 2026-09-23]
uav_cargo_refined/exports/CargoUAV_Refined_complete.step
3069.0 x 4200.0 x 938.1 mm

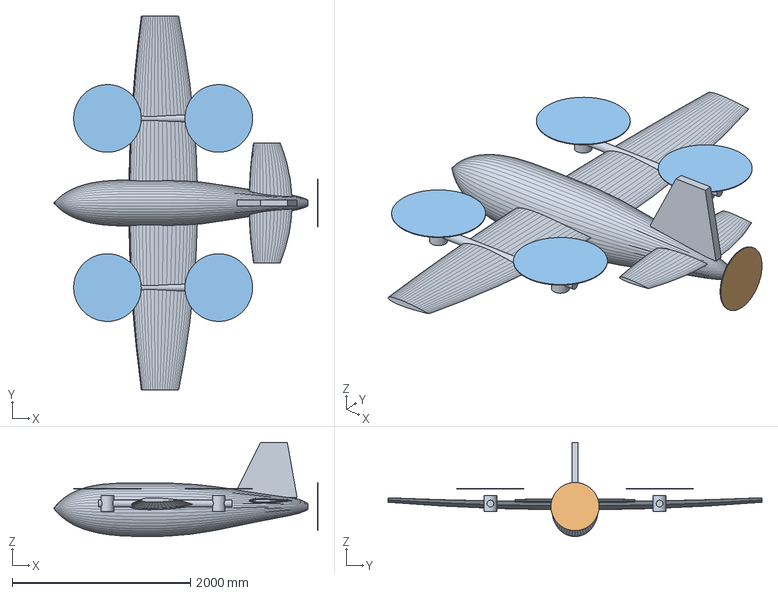
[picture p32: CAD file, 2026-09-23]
uav_cargo_vtol/exports/CargoUAV_HybridVTOL_complete.step
2964.0 x 4200.0 x 1056.9 mm

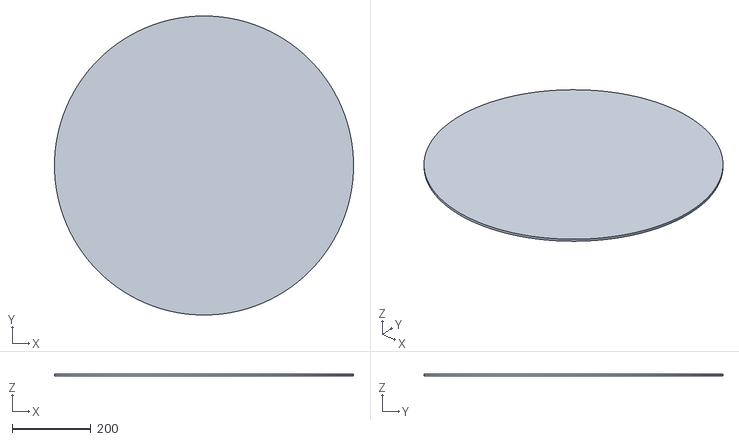
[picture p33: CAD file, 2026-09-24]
CargoUAV_cruise_v2_m_4.obj
760.0 x 759.8 x 6.00

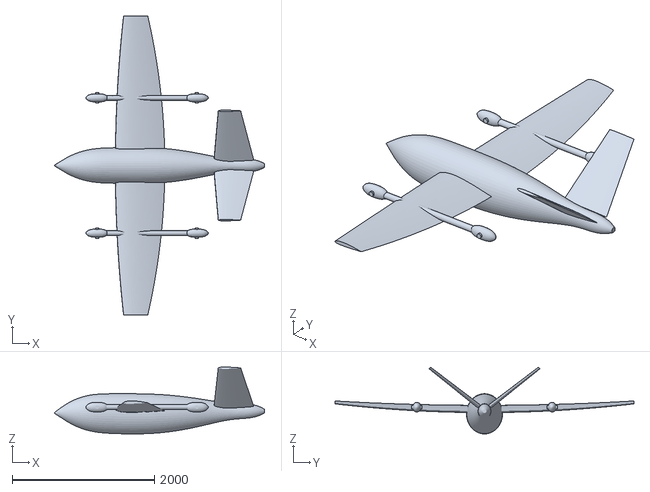
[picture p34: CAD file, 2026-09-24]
openfoam/cfd_geometry_v2/CargoUAV_cruise_v2_mm.stl
2950.0 x 4200.0 x 939.4

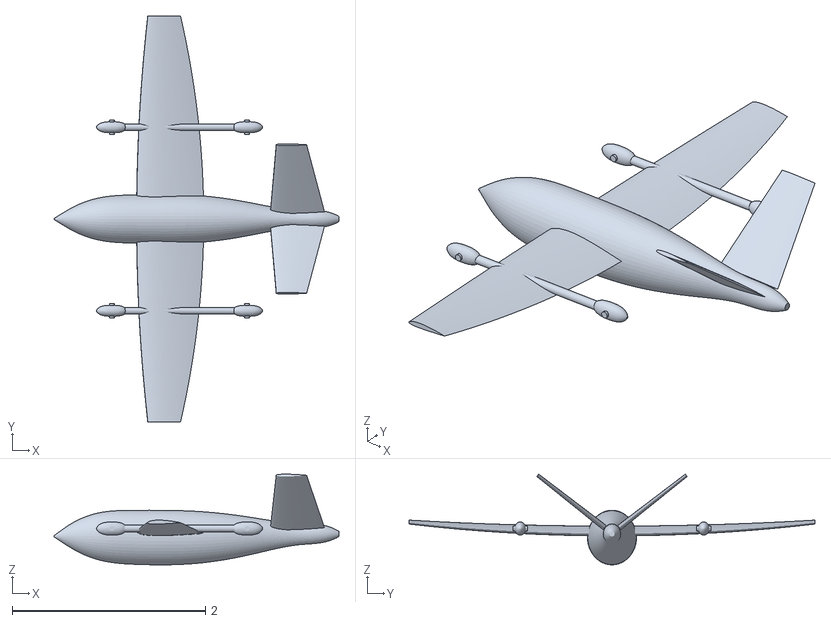
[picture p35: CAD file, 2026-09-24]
openfoam/cfd_v2_alpha_p4_coarse/constant/geometry/CargoUAV_cruise_m.stl
2.95 x 4.20 x 0.939

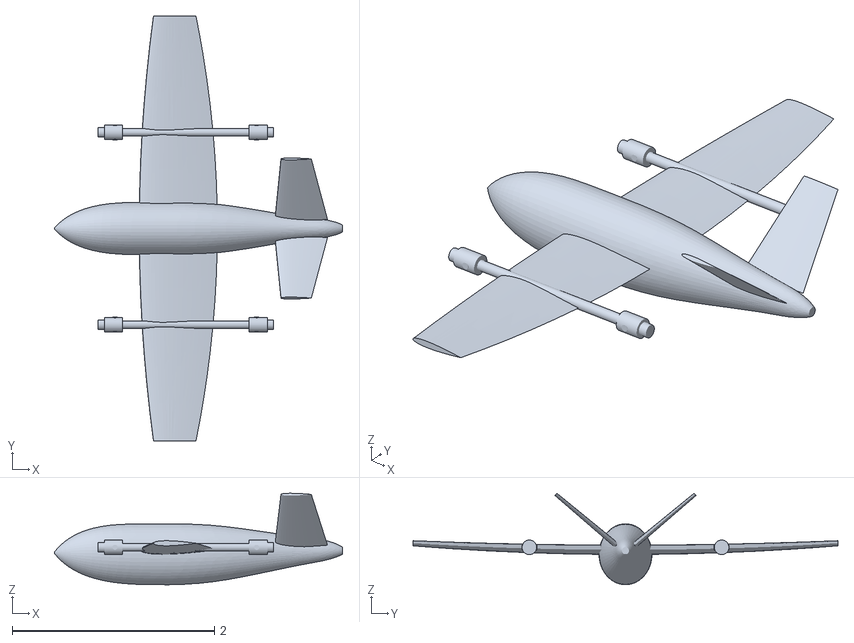
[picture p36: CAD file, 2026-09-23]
openfoam/cfd_v2_alpha_p4_fine/constant/geometry/CargoUAV_cruise_m.stl
2.85 x 4.20 x 0.904

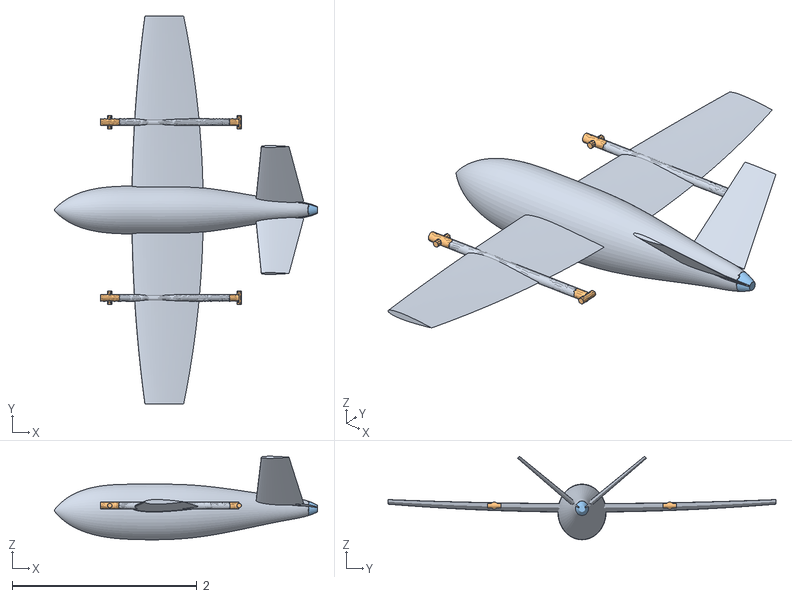
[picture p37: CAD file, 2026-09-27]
openfoam/manufacturable_mesh_families/CargoUAV_partitioned_m.stl
2.85 x 4.20 x 0.905
airframe
nacelles
pusher

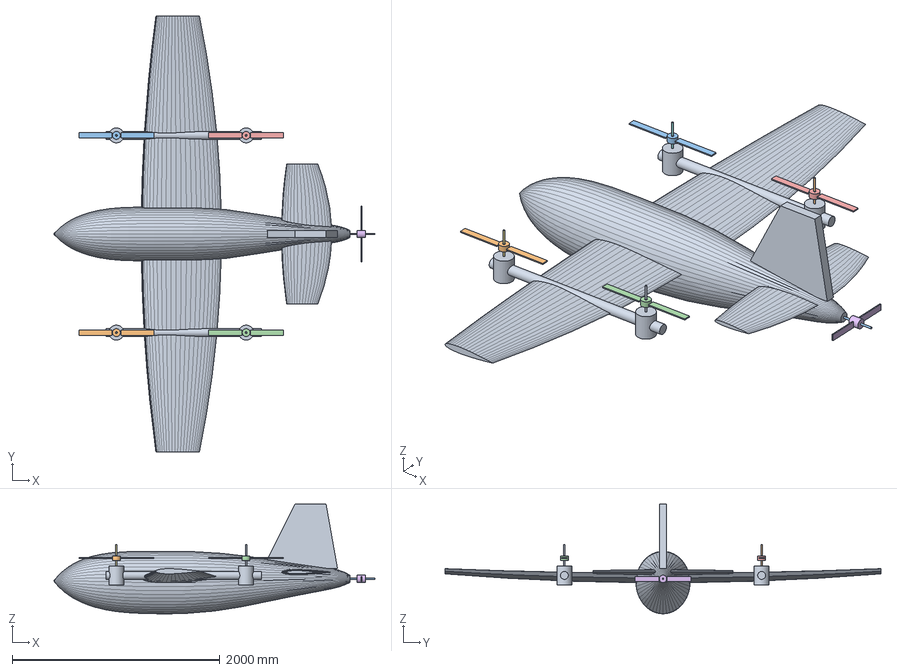
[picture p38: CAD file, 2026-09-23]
uav_cargo_animation/CargoUAV_HybridVTOL_Animated.FCStd
3090.0 x 4200.0 x 1057.0 mm
Hybrid VTOL airframe
Hub and blades — front left
Hub and blades — front right
Hub and blades — rear left
Hub and blades — rear right
Hub and blades — gasoline pusher
Axis marker — front left
Axis marker — front right
Axis marker — rear left
Axis marker — rear right
Axis marker — gasoline pusher
Centre of gravity marker and pitch axis

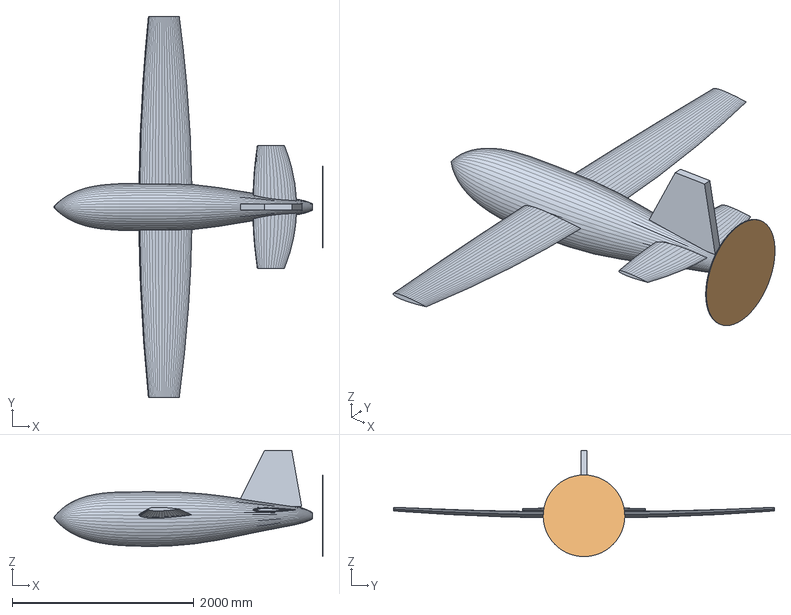
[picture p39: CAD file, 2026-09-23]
uav_cargo_freecad/CargoUAV_CFD.FCStd
2964.0 x 4200.0 x 1169.1 mm
Unified watertight airframe
Optional pusher actuator disk

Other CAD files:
openfoam/cfd_v2_alpha_p4_medium/constant/geometry/CargoUAV_cruise_mm.step
openfoam/manufacturable_mesh_families/cases/coarse/constant/geometry/CargoUAV_manufacturable_m.stl
openfoam/manufacturable_mesh_families/cases/medium/constant/geometry/CargoUAV_manufacturable_m.stl
openfoam/manufacturable_vtol/constant/geometry/CargoUAV_manufacturable_m.stl
openfoam/manufacturable_vtol_fine/constant/geometry/CargoUAV_manufacturable_m.stl
CargoUAV_cruise_v2_m_0.obj
CargoUAV_cruise_v2_m_1.obj
CargoUAV_cruise_v2_m_2.obj
CargoUAV_cruise_v2_m_3.obj
CargoUAV_cruise_v2_m_5.obj
openfoam/cfd_v2_alpha_p4_coarse/constant/geometry/CargoUAV_cruise_mm.step
openfoam/cfd_v2_alpha_p4_fine/constant/geometry/CargoUAV_cruise_mm.step
openfoam/cfd_v2_alpha_p4_noNearBody/constant/geometry/CargoUAV_cruise_mm.step
openfoam/manufacturable_mesh_families/cases/fine/constant/geometry/CargoUAV_manufacturable_m.stl
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

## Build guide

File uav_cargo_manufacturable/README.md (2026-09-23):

# Revisão fabricável dos rotores basculantes

O desenho anterior posicionava as juntas traseiras em `X=1850 mm` e inclinava todos os
pods para a frente. A análise geométrica encontrou colisão das pás traseiras a partir de
aproximadamente 75°, chegando a cerca de 200.000 mm³ de interpenetração em 90°.

Nesta revisão:

- rotores dianteiros: pivô em `X=600 mm`, basculamento para frente até `-90°`;
- rotores traseiros: pivô em `X=2000 mm`, na extremidade reforçada do boom;
- rotores traseiros basculam para trás até `+90°`;
- todas as hélices param, são indexadas a 90° e travadas antes do tilt;
- a animação impede tilt enquanto `VTOL_RPM` não for zero.

A trajetória foi verificada em incrementos de 5°. Não houve interpenetração e a menor
folga de pá encontrada foi superior a 100 mm na geometria corrigida.

Essa validação cobre somente interferência geométrica. A fabricação ainda exige projeto
do mancal, eixo, trava redundante, atuador, batentes, chicote flexível, cargas de inércia,
fadiga e tolerâncias de montagem.

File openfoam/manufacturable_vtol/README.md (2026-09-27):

# Cargo UAV fabricável — caso OpenFOAM 14

Caso preliminar de escoamento externo para a montagem completa em configuração
VTOL: fuselagem, asa, empenagem em V, quatro tilt-rotors e propulsor traseiro.

- geometria em metros: `constant/geometry/CargoUAV_manufacturable_m.stl`;
- velocidade de referência: 25 m/s;
- incidência: +4 graus;
- turbulência: RANS `kOmegaSST`;
- domínio: 26 x 20 x 14 m;
- fundo: 52 x 40 x 28 células;
- refinamento de superfície: nível 4;
- camadas prismáticas desativadas nesta primeira malha de validação.

No WSL Ubuntu:

```sh
cd /mnt/c/GitHub/sar-cargo-uav/openfoam/manufacturable_vtol
./Allmesh
```

Esta etapa verifica a malha da montagem completa. Uma campanha física de cruzeiro
deve posteriormente separar hélices/discos atuadores e acrescentar camadas de parede.

## Benchmark no Xeon

Copie o projeto para o Xeon com o diretório `constant/polyMesh` incluído e execute:

```sh
cd openfoam/manufacturable_vtol
bash benchmark_xeon.sh 10 1500 xeon_10ranks
```

O script cria um caso isolado em `benchmark_runs/`, registra CPU, memória, versão do
OpenFOAM e mede apenas o tempo do solver. Comece com 10 ranks para comparação direta
com o baseline do Core 7 240H; depois repita com outras contagens de ranks para medir
escalabilidade do Xeon.

Compare os resultados com:

```sh
python3 compare_benchmarks.py benchmark_runs/xeon_10ranks
```

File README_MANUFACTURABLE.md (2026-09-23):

# UAV híbrido VTOL — revisão geométrica fabricável

Esta revisão corrige a colisão dos rotores traseiros com os próprios booms durante o
basculamento.

## Geometria corrigida

- juntas dianteiras em `X=600 mm`, basculando para frente até `-90°`;
- juntas traseiras em `X=2000 mm`, instaladas na extremidade estrutural dos booms;
- conjuntos traseiros basculando para trás até `+90°`;
- cauda em V mantida, com painéis a 40°;
- hélices obrigatoriamente paradas, indexadas e travadas antes do movimento dos pods.

A trajetória das pás foi testada geometricamente em incrementos de 5°. O resultado foi:

- nenhuma interpenetração nos quatro conjuntos;
- folga mínima dos conjuntos dianteiros: aproximadamente 38 mm;
- folga mínima dos conjuntos traseiros: aproximadamente 107 mm;
- desenho anterior: colisão traseira a partir de aproximadamente 75°.

## Animação

Abra `CargoUAV_HybridVTOL_Manufacturable.FCStd` e execute
`RunManufacturableTransition.FCMacro`.

A sequência liga a pusher mantendo os pods verticais, transfere sustentação para a asa,
para os rotores elétricos, indexa as pás, confirma a trava e só então aplica tilt
espelhado. Use `StopManufacturableTransition.FCMacro` para retornar ao solo.

## Limite desta verificação

Ausência de colisão no CAD não torna o mecanismo pronto para fabricação. Ainda devem ser
dimensionados mancais, eixos, suportes, atuadores, batentes, pinos de trava, sensores de
posição, chicotes flexíveis, rigidez, fadiga e tolerâncias. A folga dianteira de 38 mm
deve ser ampliada ou justificada após considerar flexão estrutural e tolerâncias reais.

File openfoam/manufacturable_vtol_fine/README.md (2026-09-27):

# Cargo UAV — malha refinada

Caso derivado de `manufacturable_vtol`, preservando o baseline de 160.471 células.

- fundo: 52 x 40 x 28 células;
- superfície e arestas do UAV: nível 5;
- região próxima ao corpo: nível 2;
- limite global: 3 milhões de células;
- camadas prismáticas ainda desativadas para isolar o efeito do refinamento;
- solver: `incompressibleFluid`, RANS `kOmegaSST`;
- ponto: 25 m/s e +4 graus;
- execução: 1.500 iterações, 10 ranks MPI.

Os resultados devem ser comparados com `manufacturable_vtol` usando a média das
100 iterações finais e o tempo de parede informado pelo solver.

A execução concluída e a comparação estão documentadas em
`REFINED_MESH_REPORT.md`; os mesmos números estão disponíveis em formato legível
por máquina em `refined_results.json`.

## Execução no Xeon de 20 núcleos

Com OpenFOAM 14 disponível em `/opt/openfoam14`, execute:

```sh
bash run_xeon_20cores.sh 1500 xeon_20cores
```

O script usa 20 ranks MPI, fixa um rank por núcleo, registra a configuração de
hardware, mede somente o solver e gera `XEON_RESULT_SUMMARY.md`. Cada execução é
isolada em `benchmark_runs/` e não sobrescreve resultados existentes.

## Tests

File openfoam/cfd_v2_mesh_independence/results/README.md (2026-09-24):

# Resultados gerados

Após as execuções, `scripts/extract_results.py` cria nesta pasta:

- `mesh_independence.csv`: métricas por nível;
- `MESH_COMPARISON.md`: comparação e variações percentuais.

Esses arquivos são derivados e estão ignorados pelo Git.

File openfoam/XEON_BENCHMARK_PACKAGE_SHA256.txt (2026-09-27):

88CBD6C46FECA83A6E90C1760C473A8FB0F7D5C5C55171F21BB622374D5D2AE0  CargoUAV_Xeon_Benchmark_Package.zip

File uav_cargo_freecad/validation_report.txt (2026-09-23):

Cargo UAV geometry validation (FreeCAD)
=======================================
Airframe: {'valid': True, 'closed': True, 'solids': 1, 'shells': 1, 'faces': 240, 'volume_mm3': 533691098.1287754, 'area_mm2': 9031567.237592628, 'bbox_mm': (2850.0, 4200.0, 1056.7150510045149)}
Propeller disk: {'valid': True, 'closed': True, 'solids': 1, 'shells': 1, 'faces': 3, 'volume_mm3': 5089380.098815465, 'area_mm2': 1294964.4918097127, 'bbox_mm': (8.0, 899.7202638007348, 900.0)}
FreeCAD: ['1', '1', '3', '20260725 (Git shallow)', 'Unknown', '2026/07/25 04:52:02', 'grafted,grafted', '145529fe741292ff0b3977a01195bf0247425794']

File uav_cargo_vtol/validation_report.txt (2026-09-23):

Hybrid VTOL cargo UAV geometry validation
=========================================
Airframe: {'valid': True, 'closed': True, 'solids': 1, 'faces': 336, 'volume_mm3': 603275235.0803672, 'bbox_mm': (2850.0, 4200.0, 1056.7150510045149)}
Pusher disk: {'valid': True, 'closed': True, 'solids': 1, 'faces': 3, 'volume_mm3': 1832176.8355735675, 'bbox_mm': (8.0, 539.8321582804408, 540.0)}
VTOL disks: {'valid': True, 'closed': True, 'solids': 4, 'faces': 12, 'volume_mm3': 10887503.500280784, 'bbox_mm': (2010.0, 2659.76377832062, 6.0)}
Wing area: 2.604 m2
Aspect ratio: 6.774
FreeCAD: ['1', '1', '3', '20260725 (Git shallow)', 'Unknown', '2026/07/25 04:52:02', 'grafted,grafted', '145529fe741292ff0b3977a01195bf0247425794']

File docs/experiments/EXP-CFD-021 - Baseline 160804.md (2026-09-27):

---
id: EXP-CFD-021
type: experiment
project: SAR-CARGO-UAV
domain: CFD
status: investigation
cells: 160804
concave_cells: 5416
---

# EXP-CFD-021 — Baseline 160804

## Resultado

| Métrica | Valor |
|---|---:|
| Cells | 160804 |
| Aspect ratio máximo | 5.208878 |
| Non-orthogonality máxima | 54.70829° |
| Non-orthogonality média | 8.046341° |
| Skewness máxima | 3.611411 |
| Concave faces | 178 |
| Concave cells | 5416 |

## checkMesh

**FAILED — 1 mesh check**

## Relacionado

[[ISS-CFD-001 - Concave Cells]]

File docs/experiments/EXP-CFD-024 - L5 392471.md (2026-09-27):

---
id: EXP-CFD-024
type: experiment
project: SAR-CARGO-UAV
domain: CFD
status: investigation
cells: 392471
concave_cells: 13893
---

# EXP-CFD-024 — L5 392471

## Objetivo

Verificar se um refinamento significativamente maior reduziria os problemas geométricos.

## Resultado

| Métrica | Valor |
|---|---:|
| Cells | 392471 |
| Concave cells | 13893 |
| Non-orthogonality máxima | ~45.7° |
| Skewness máxima | ~2.49 |

## Resultado do checkMesh

**FAILED — 1 mesh check**

## Conclusão

O aumento de aproximadamente 160 mil para 392 mil células não eliminou o problema.

## Lição derivada

[[LES-CFD-004 - More Refinement Does Not Guarantee Better Mesh]]

## Issue relacionado

[[ISS-CFD-001 - Concave Cells]]

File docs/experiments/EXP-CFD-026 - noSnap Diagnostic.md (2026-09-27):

---
id: EXP-CFD-026
type: experiment
project: SAR-CARGO-UAV
domain: CFD
status: diagnostic
cells: 160804
concave_cells: 7353
---

# EXP-CFD-026 — noSnap Diagnostic

## Objetivo

Determinar se o processo de snap era a principal origem das células côncavas.

## Configuração

Snap desabilitado.

## Resultado

| Métrica | Valor |
|---|---:|
| Cells | 160804 |
| Hexahedra | 149476 |
| Polyhedra | 11328 |
| Aspect ratio máximo | 1 |
| Non-orthogonality máxima | 25.2394° |
| Non-orthogonality média | 7.473587° |
| Skewness máxima | 0.3333333 |
| Concave cells | 7353 |

## checkMesh

**FAILED — 1 mesh check**

## Conclusão

As células côncavas já existem antes do processo de snap.

## Lição derivada

[[LES-CFD-008 - Concave Cells Exist Before Snap]]

## Issue relacionado

[[ISS-CFD-001 - Concave Cells]]

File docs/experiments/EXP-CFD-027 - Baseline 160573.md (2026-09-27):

---
id: EXP-CFD-027
type: experiment
project: SAR-CARGO-UAV
domain: CFD
status: investigation
date: 2026-09-27
case_path: openfoam/cfd_v2_alpha_p4_noNearBody
openfoam: 14
velocity_ms: 25
aoa_deg: 4
cells: 160573
concave_cells: 5108
concave_faces: 213
warped_faces: 8
max_non_orthogonality_deg: 49.57469
max_skewness: 2.21152
tags:
  - CFD
  - OpenFOAM
  - mesh
---

# EXP-CFD-027 — Baseline 160573

## Case físico

`openfoam/cfd_v2_alpha_p4_noNearBody`

## Resultado

| Métrica | Valor |
|---|---:|
| Cells | 160573 |
| Faces | 505925 |
| Points | 185655 |
| Aspect ratio máximo | 5.062653 |
| Non-orthogonality máxima | 49.57469° |
| Non-orthogonality média | 7.962141° |
| Skewness máxima | 2.21152 |
| Concave faces | 213 |
| Ângulo côncavo máximo | 58.4278° |
| Warped faces | 8 |
| Concave cells | 5108 |

## checkMesh

**FAILED — 1 mesh check**

## Arquivos de diagnóstico

Gerados com:

`checkMesh -allGeometry -allTopology -writeSurfaces -surfaceFormat vtk`

Resultados:

- `concaveCells.vtk`
- `concaveFaces.vtk`
- `warpedFaces.vtk`

## Disposição de engenharia

**INVESTIGATION ONLY**

Esta malha não deve ser tratada como baseline aerodinâmica final.

## Issue

[[ISS-CFD-001 - Concave Cells]]

## Decisão

[[ADR-CFD-008 - Retessellate Geometry]]

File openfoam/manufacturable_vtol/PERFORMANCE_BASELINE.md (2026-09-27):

# Baseline de desempenho — Core 7 240H

Data: 2026-09-27

## Ambiente

- CPU do host: Intel Core 7 240H, 10 núcleos / 16 processadores lógicos;
- CPU exposta ao WSL2: 8 núcleos / 16 threads;
- memória disponível no WSL2: 15 GiB;
- sistema: WSL2 Ubuntu 22.04;
- OpenFOAM: versão 14;
- ranks MPI: 10, com `--oversubscribe`;
- malha: 160.471 células;
- solver: `incompressibleFluid`, RANS `kOmegaSST`;
- iterações: 1.500.

## Tempo

- `ClockTime` informado pelo solver: 254 s;
- `ExecutionTime` informado pelo processo principal: 194,22 s;
- desempenho baseado em tempo de parede: 5,91 iterações/s;
- tempo por iteração: 0,169 s;
- throughput de referência: aproximadamente 0,948 milhão de células-iteração/s.

Para comparação entre máquinas, usar o `ClockTime`, o mesmo número de ranks, a
mesma malha e a mesma quantidade de iterações. O tempo de preparação, decomposição
e reconstrução não está incluído no tempo do solver acima.

## Resultado aerodinâmico

Média das 100 iterações finais:

| Coeficiente | Média | Desvio padrão | Mínimo | Máximo |
|---|---:|---:|---:|---:|
| `Cd` | 0,045821 | 0,000509 | 0,045275 | 0,046852 |
| `Cl` | 0,280022 | 0,006313 | 0,270416 | 0,289223 |
| `Cm` | -0,029070 | 0,006476 | -0,045466 | -0,020834 |

Os coeficientes ainda apresentam oscilação na janela final. A execução serve como
baseline de desempenho e resultado preliminar, não como solução aerodinâmica final.

## Parede

- `y+` mínimo: 18,48;
- `y+` máximo: 379,02;
- `y+` médio no último passo do solver: 129,94;
- `y+` médio recalculado após reconstrução: 134,65.

A malha não possui camadas prismáticas; esses valores confirmam que uma malha de
parede de maior fidelidade será necessária para o resultado final.

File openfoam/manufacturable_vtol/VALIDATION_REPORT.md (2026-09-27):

# Validação inicial — montagem fabricável no OpenFOAM 14

## Geometria

- STL binário convertido de milímetros para metros;
- 84.446 triângulos e 42.225 vértices;
- dimensões: 2,850 x 4,200 x 0,905 m;
- superfície fechada, uma região conectada;
- nenhuma face ilegal, borda aberta ou borda não-manifold.

## Malha preliminar

- `blockMesh`: 58.240 células;
- `snappyHexMesh`: 160.471 células;
- patch do UAV: 10.198 faces;
- não ortogonalidade máxima: 46,28 graus;
- não ortogonalidade média: 7,90 graus;
- skewness máxima: 3,17;
- aspect ratio máximo: 5,45;
- volume mínimo: 4,51e-6 m3;
- `checkMesh`: `Mesh OK`.

## Smoke test

O solver `incompressibleFluid` com `kOmegaSST` completou 10 iterações em série,
confirmando a leitura da malha, das condições de contorno e do cálculo de forças.
Os coeficientes da iteração 10 foram `Cd = 0,02262`, `Cl = -0,01362` e
`Cm = 0,00395`. Esses valores são apenas transitórios e não representam uma
solução convergida.

O valor inicial de `y+` ficou entre 12,97 e 134,27, com média 51,82. Isso é
esperado porque esta primeira malha não possui camadas prismáticas; ela não deve
ser usada para dimensionamento aerodinâmico final.

## Execução completa

A campanha de 1.500 iterações foi concluída em 10 ranks MPI. O solver informou
`ClockTime = 254 s` e `ExecutionTime = 194,22 s`. A média das 100 iterações finais
foi `Cd = 0,045821`, `Cl = 0,280022` e `Cm = -0,029070`. Os respectivos desvios
padrão foram 0,000509, 0,006313 e 0,006476.

Os coeficientes permanecem oscilatórios na janela final, principalmente `Cl` e
`Cm`. A solução é adequada como baseline computacional e avaliação preliminar,
mas não deve ser tratada como resultado aerodinâmico convergido de alta fidelidade.

No passo 1.500, o solver registrou `y+` entre 18,48 e 379,02, com média de área
129,94. O pós-processamento do campo reconstruído calculou média 134,65.

Os detalhes reproduzíveis de hardware e desempenho estão em
`PERFORMANCE_BASELINE.md` e `baseline_core7_240h_10ranks.json`.

## Próxima etapa

Executar a solução até convergência e, em seguida, preparar uma malha de maior
fidelidade com camadas de parede. Para representar propulsão, os rotores devem ser
separados em patches próprios e modelados por disco atuador, MRF ou malha móvel.

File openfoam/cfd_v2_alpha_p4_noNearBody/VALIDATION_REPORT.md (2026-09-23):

# Relatório da primeira validação CFD

## Caso executado

- OpenFOAM 14 no WSL Ubuntu 22.04
- Escoamento externo estacionário e incompressível
- Velocidade: 25 m/s
- Ângulo de ataque geométrico: 0°
- Turbulência: RANS `kOmegaSST`
- Hélices e forças propulsivas: não incluídas
- Área de referência: 2,604 m²
- Corda média: 0,6415 m
- Centro de momentos: X = 1,07 m

## Geometria

- STL: 10.258 triângulos
- Dimensões: 2,85 × 4,20 × 0,904 m
- Superfície fechada, uma região conectada
- Nenhum triângulo ilegal ou aresta aberta

## Malha preliminar

- 269.773 células
- Não ortogonalidade: máxima 60,45°, média 7,36°
- Skewness máxima: 3,981
- Aspect ratio máximo: 6,19
- `checkMesh` padrão: `Mesh OK`
- Sem camadas prismáticas nesta primeira rodada
- A verificação `-allGeometry -allTopology` registra 8.799 células côncavas;
  esta limitação precisa ser reduzida na malha de fidelidade seguinte.

## Resultado preliminar

Média das iterações 140–150:

| Coeficiente | Média | Faixa observada |
|---|---:|---:|
| CM | 0,010913 | 0,000069 |
| CD | 0,065456 | 0,000029 |
| CL | -0,012470 | 0,000078 |

O valor de sustentação próximo de zero é coerente com o caso a 0° e com a
incidência geométrica atual. Estes números ainda não devem ser usados para
dimensionamento, pois faltam estudo de independência de malha, camadas de parede,
avaliação de `y+`, varredura de ângulo de ataque e modelagem propulsiva.

## Próximas validações

1. Gerar malha com camadas prismáticas consistentes e reduzir células côncavas.
2. Executar incidências de -4° a 12° em passos de 2°.
3. Comparar malhas grossa, média e fina.
4. Verificar `y+` e ajustar a primeira altura de camada.
5. Acrescentar o pusher como disco atuador ou região MRF.
6. Tratar o modo VTOL em caso transiente separado.

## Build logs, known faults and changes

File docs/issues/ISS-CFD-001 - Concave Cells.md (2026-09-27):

---
id: ISS-CFD-001
type: issue
project: SAR-CARGO-UAV
domain: CFD
status: open
severity: high
tags:
  - CFD
  - OpenFOAM
  - mesh
---

# ISS-CFD-001 — Concave Cells

## Problema

As malhas atuais do SAR Cargo UAV apresentam milhares de células côncavas.

## Evidências

- [[EXP-CFD-021 - Baseline 160804]]
- [[EXP-CFD-024 - L5 392471]]
- [[EXP-CFD-026 - noSnap Diagnostic]]
- [[EXP-CFD-027 - Baseline 160573]]

## Interpretação atual

O problema não parece estar associado exclusivamente ao processo de snap.

A geometria superficial e a tesselação STEP → STL são atualmente os principais suspeitos.

## Lição relacionada

[[LES-CFD-008 - Concave Cells Exist Before Snap]]

## Decisão atual

[[ADR-CFD-008 - Retessellate Geometry]]

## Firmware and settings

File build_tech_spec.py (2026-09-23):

from __future__ import annotations

import csv
import re
import shutil
from dataclasses import dataclass
from datetime import date
from pathlib import Path

from docx import Document
from docx.enum.section import WD_ORIENT
from docx.enum.table import WD_CELL_VERTICAL_ALIGNMENT, WD_TABLE_ALIGNMENT
from docx.enum.text import WD_ALIGN_PARAGRAPH
from docx.oxml import OxmlElement
from docx.oxml.ns import qn
from docx.shared import Cm, Pt, RGBColor


ROOT = Path(__file__).resolve().parent
OUT = ROOT / "Tech Spec"
DS_DIR = OUT / "Data sheets"


@dataclass
class Part:
    ident: str
    category: str
    item: str
    qty: str
    maturity: str
    candidate: str
    purpose: str
    requirements: str
    interfaces: str
    acceptance: str
    dependencies: str
    source: str


def p(category, item, qty, maturity, candidate, purpose, requirements,
      interfaces, acceptance, dependencies="Nenhuma adicional.", source="Ficha do fornecedor a exigir antes da compra."):
    ident = f"DS-{len(PARTS)+1:03d}"
    PARTS.append(Part(ident, category, item, qty, maturity, candidate, purpose,
                      requirements, interfaces, acceptance, dependencies, source))


PARTS: list[Part] = []

# A — Aviónica e missão
p("Aviónica", "Controlador de voo", "1", "Arquitetura aceita", "Holybro Pixhawk 6X",
  "Controle de voo, navegação, failsafes e registro primário.",
  "Autopiloto classe H7, IMUs redundantes, barômetros redundantes, CAN, Ethernet e entradas de alimentação redundantes.",
  "MAVLink/CAN/UART; 5 V regulados; servo rail isolado.",
  "Teste de alimentação A/B, sensores, logging, watchdog, RTL e perda de enlace.",
  "Firmware ArduPilot/PX4 e integração do sistema de energia.",
  "https://docs.holybro.com/autopilot/pixhawk-6x/technical-specification")
p("Aviónica", "Computador de missão", "1", "Arquitetura aceita", "Raspberry Pi 5 — 8 GB",
  "Visão computacional, comunicações de alto nível e processamento de missão.",
  "BCM2712, 8 GB, alimentação 5 V/5 A, refrigeração ativa e desligamento controlado.",
  "Ethernet/USB/UART com Pixhawk; câmera CSI; armazenamento local.",
  "Burn-in de 4 h, carga de CPU, perda/retorno de energia e temperatura no compartimento.",
  "Conversores DC/DC redundantes e solução térmica.",
  "https://datasheets.raspberrypi.com/rpi5/raspberry-pi-5-product-brief.pdf")
p("Aviónica", "Refrigerador do computador", "1", "Candidato", "Raspberry Pi Active Cooler",
  "Manter o computador de missão abaixo do limite térmico.",
  "Compatível com Raspberry Pi 5; operação contínua na temperatura interna prevista.",
  "Conector de fan do Raspberry Pi 5; fluxo de ar desobstruído.",
  "Teste térmico em solo com CPU a 100% e fuselagem fechada.",
  "Projeto de dutos/ventilação.", "https://www.raspberrypi.com/products/active-cooler/")
p("Aviónica", "Módulo GNSS/RTK + magnetômetro", "1", "Candidato", "Holybro H-RTK NEO-F9P + RM3100",
  "Posição, velocidade, rumo e possibilidade de RTK.",
  "Dupla banda GNSS, RTK, magnetômetro RM3100; 4,75–5,25 V; massa aproximada 39 g.",
  "CAN/UART conforme variante; montagem afastada de potência e ignição.",
  "Aquisição a céu aberto, comparação de rumo, interferência com motor a gasolina ligado.",
  "Mastro e plano de aterramento eletromagnético.",
  "https://docs.holybro.com/gps-and-rtk-system/h-rtk-neo-f9p-series-rm3100-compass/specification")
p("Aviónica", "Sensor de velocidade do ar + pitot", "1", "Candidato", "Holybro MS5525",
  "Medição de velocidade indicada e proteção do envelope.",
  "Sensor diferencial digital, faixa adequada ao voo de 15–40 m/s, tubos resistentes a combustível/calor.",
  "I²C/CAN via interface; tomadas de pressão total/estática.",
  "Calibração zero, teste de vazamento, comparação em túnel/veículo.",
  "Posição do pitot fora da esteira das hélices.",
  "https://docs.holybro.com/peripherals/ms4525do-and-ms5525dso-i2c-airspeed-sensor")
p("Aviónica", "Altímetro laser", "1", "Candidato", "LightWare SF11/C",
  "Altura precisa na decolagem e no pouso VTOL.",
  "Faixa 0,2–100 m, 20 Hz, precisão aproximada ±0,1 m, 5 V, massa aproximada 35 g.",
  "Serial/I²C; campo de visão desobstruído para baixo.",
  "Teste em superfícies clara/escura, poeira e inclinação; comparação com referência.",
  "Janela óptica e suporte antivibração.",
  "https://lightwarelidar.com/wp-content/uploads/2025/07/SF11-Laser-Altimeter-Manual-Rev-10.pdf")
p("Missão", "Câmera RGB", "1", "Candidato", "Raspberry Pi Camera Module 3 Wide",
  "Busca visual, registro e apoio à navegação.",
  "Sony IMX708, 12 MP, autofoco, variante wide; proteção óptica substituível.",
  "CSI para Raspberry Pi 5.",
  "Foco, exposição, vibração, rolling shutter e gravação sustentada.",
  "Cabo CSI com comprimento final e janela frontal.",
  "https://datasheets.raspberrypi.com/camera/camera-module-3-product-brief.pdf")
p("Missão", "Câmera térmica", "1", "Opcional / candidato", "Teledyne FLIR Boson 320 ou 640",
  "Detecção térmica de pessoas em missão de resgate.",
  "Núcleo 12 µm, resolução selecionada por alcance/ orçamento, consumo e lente compatíveis com a missão.",
  "USB/serial/vídeo conforme variante; montagem estabilizada ou fixa.",
  "Teste de alcance de detecção, latência, temperatura e gravação sincronizada.",
  "Definir requisito operacional de alcance e lente.", "https://www.oem.flir.com/products/boson/")
p("Aviónica", "Armazenamento de missão", "2", "TBD", "microSD High Endurance ou NVMe industrial",
  "Sistema operacional e logs redundantes.",
  "Alta resistência de escrita, temperatura industrial preferencial, capacidade ≥128 GB.",
  "microSD ou M.2 HAT; imagem de recuperação documentada.",
  "Teste SMART/velocidade, 8 h de escrita e recuperação após corte de energia.",
  "Escolha final do gabinete do Raspberry Pi.")
p("Aviónica", "Buzzer e localizador", "1", "TBD", "Buzzer ativo + beacon independente",
  "Localização da aeronave e indicação de estado.",
  "Audível a longa distância; alimentação independente ou reserva; baixo consumo em espera.",
  "GPIO/PWM e bateria reserva.",
  "Teste de autonomia, alcance audível e acionamento após falha do barramento.")
p("Aviónica", "Módulo de relógio RTC", "1", "TBD", "RTC industrial com bateria/supercapacitor",
  "Preservar tempo de logs sem GNSS/rede.",
  "Baixa deriva, interface compatível com computador de missão.",
  "I²C; bateria substituível ou supercapacitor.",
  "Teste de deriva por 7 dias e retomada após corte total.")

# B — Comunicação
p("Comunicação", "Rádio telemetria de bordo", "1", "Candidato", "RFD900x-BR",
  "Telemetria MAVLink de longo alcance.",
  "Versão homologada/adequada ao Brasil, 5 V, diversidade e potência configurável.",
  "UART para Pixhawk; duas antenas afastadas de fontes EMI.",
  "Teste de enlace, failsafe, corrente em TX máximo e alcance progressivo.",
  "Confirmar homologação ANATEL e plano de frequências.",
  "https://rfdesign.com.au/wp-content/uploads/2024/04/RFD900x-DataSheet-V1.2.pdf")
p("Comunicação", "Rádio telemetria de solo", "1", "Candidato", "RFD900x-BR USB",
  "Par do rádio embarcado para a estação de controle.",
  "Mesma banda/firmware; interface USB; antenas compatíveis.",
  "USB para estação de solo.",
  "Teste de pareamento, atualização, RSSI e recuperação de perda.",
  "Mesmo lote/região do rádio de bordo.",
  "https://store.rfdesign.com.au/all-products/")
p("Comunicação", "Conjunto de antenas e cabos RF", "1 kit", "TBD", "Antenas 900 MHz + cabos coaxiais",
  "Radiar/receber telemetria com baixa perda.",
  "Impedância 50 Ω, VSWR documentado, conectores corretos, cabos de baixa perda.",
  "SMA/RP-SMA conforme modem; montagem ortogonal/diversidade.",
  "Medição de continuidade/VSWR e teste de alcance.",
  "Definir instalação e conectores antes da compra.")
p("Comunicação", "Modem 4G", "1", "Candidato", "Waveshare SIM7600G-H 4G HAT",
  "Canal secundário de dados e supervisão quando houver cobertura.",
  "LTE Cat-4 global; confirmar bandas da operadora brasileira; GNSS do modem não substitui GNSS de voo.",
  "USB para Raspberry Pi; alimentação 5 V com picos suportados.",
  "Teste de bandas, handover, consumo de pico e perda de rede.",
  "SIM/plano de dados e cobertura operacional.", "https://www.waveshare.com/SIM7600G-H-4G-HAT.htm")
p("Comunicação", "Antenas LTE/GNSS do modem", "1 kit", "TBD", "Antenas compatíveis com SIM7600",
  "Comunicação celular e GNSS auxiliar.",
  "Bandas brasileiras, 50 Ω, conectores corretos e instalação distante da ignição.",
  "U.FL/SMA conforme chicote.",
  "VSWR, cobertura e interferência com demais rádios.")

# C — Propulsão VTOL e tilt
p("Propulsão VTOL", "Motor elétrico de sustentação", "4", "Candidato — compra bloqueada", "T-Motor U10 II KV100",
  "Sustentação VTOL e, quando comandado, contribuição elétrica na transição.",
  "12S; massa aproximada 415 g; compatível com hélice 30×10,5; margem térmica e empuxo final validados em bancada.",
  "ESC trifásico; flange estrutural; sensor de rotação recomendado.",
  "Curva empuxo/corrente, temperatura, vibração, balanceamento e falha de um motor.",
  "MTOW fechado e razão empuxo/peso VTOL ≥1,5.", "https://store.tmotor.com/product/u10-2-u-efficiency.html")
p("Propulsão VTOL", "ESC dos motores de sustentação", "4", "Candidato — compra bloqueada", "T-Motor ALPHA 80A 12S",
  "Comutação e controle dos quatro motores VTOL.",
  "12S, corrente contínua e refrigeração compatíveis com curva real; telemetria desejável.",
  "Bateria 12S, motor U10 II, PWM/DShot conforme integração.",
  "Bancada em potência máxima, rampa, corte, perda de sinal e temperatura.",
  "Curva final de hélice/motor e projeto de ventilação.", "https://store.tmotor.com/product/alpha-80a-12s-esc.html")
p("Propulsão VTOL", "Hélice VTOL CW 30×10,5", "2 + 1 reserva", "Candidato — compra bloqueada", "T-Motor G30×10.5 CW",
  "Gerar empuxo vertical com sentido de rotação balanceado.",
  "Carbono, diâmetro/passo compatíveis, limite de RPM documentado.",
  "Hub do U10 II; envelope livre em todas as posições de tilt.",
  "Balanceamento estático/dinâmico, inspeção e prova de overspeed controlada.",
  "Validação geométrica de folga.")
p("Propulsão VTOL", "Hélice VTOL CCW 30×10,5", "2 + 1 reserva", "Candidato — compra bloqueada", "T-Motor G30×10.5 CCW",
  "Gerar empuxo vertical com cancelamento de torque.",
  "Carbono, geometria espelhada e limite de RPM documentado.",
  "Hub do U10 II; envelope livre em todas as posições de tilt.",
  "Balanceamento estático/dinâmico, inspeção e prova de overspeed controlada.",
  "Validação geométrica de folga.")
p("Tilt-rotor", "Atuador de inclinação da nacele", "4", "TBD crítico", "Atuador eletromecânico industrial com feedback absoluto",
  "Girar motores dianteiros para frente e traseiros para trás somente com hélices seguras.",
  "Torque com fator ≥2 sobre pior carga aerodinâmica/inercial; feedback absoluto; retenção sem energia; baixa folga.",
  "Alimentação dedicada; CAN/PWM; eixo e mancais da nacele.",
  "Ciclagem ≥10.000, torque, folga, vibração, falha de energia e posição.",
  "Cargas de transição e projeto mecânico dos pivôs.")
p("Tilt-rotor", "Trava mecânica da nacele", "4", "TBD crítico", "Pino/trava fail-safe com sensor duplo",
  "Imobilizar cada nacele em VTOL e cruzeiro sem depender do torque do atuador.",
  "Fail-safe, confirmação independente de engate, resistência com fator estrutural definido.",
  "Interlock do controlador; batentes estruturais.",
  "Carga limite/última, engate contaminado, falha simples de sensor e 10.000 ciclos.",
  "Geometria do pivô e cargas finais.")
p("Tilt-rotor", "Sensor de indexação/parada da hélice", "4", "TBD crítico", "Encoder/Hall redundante",
  "Confirmar RPM zero e posição angular segura antes do movimento da nacele.",
  "Detecção redundante de velocidade zero e ângulo; imunidade EMI; resolução suficiente para folga estrutural.",
  "Motor/ESC e controlador de intertravamento.",
  "Falha de sensor, falso zero, parada fora da janela e vibração.",
  "Definir posição segura de cada pá no CAD.")
p("Tilt-rotor", "Mancais e eixo do pivô", "4 kits", "TBD crítico", "Rolamentos selados + eixo 7075/aço",
  "Suportar a nacele e transferir empuxo/cargas para a estrutura.",
  "Vida e carga radial/axial calculadas; baixa folga; vedação contra poeira/água.",
  "Nacele, trava, atuador e longarina/boom.",
  "Carga limite, inspeção de folga e ciclagem.",
  "Análise estrutural e desenhos liberados.")

# D — Cruzeiro a gasolina e geração
p("Propulsão cruzeiro", "Motor a gasolina pusher", "1", "Candidato — compra bloqueada", "DLE35RA",
  "Propulsão principal de cruzeiro após atingir altitude/condições de transição.",
  "34,9 cm³; potência declarada 4,1 hp a 8.500 rpm; ignição 4,8–8,4 V; combustível 30:1 conforme fabricante.",
  "Firewall traseiro, hélice pusher, tanque, servo de aceleração, ignição e escapamento.",
  "Amaciamento, curva de empuxo/consumo, partida em voo simulada, temperatura e vibração.",
  "Arrasto/potência de cruzeiro, partida pelo vento e orçamento de combustível.", "https://dlengine.com/en/rcengine/dle35ra")
p("Propulsão cruzeiro", "Hélice pusher", "2", "TBD crítico", "19×8 ou 20×8 pusher compatível",
  "Converter potência do DLE35RA em empuxo de cruzeiro.",
  "Orientação pusher real, material e RPM compatíveis; folga de fuselagem/cauda.",
  "Cubo do motor e spinner se aplicável.",
  "Balanceamento, empuxo/consumo, ruído e overspeed; uma unidade como reserva.",
  "Curva motor-hélice e instalação final.")
p("Propulsão cruzeiro", "Servo de aceleração", "1", "TBD", "Servo HV metal gear",
  "Controle do carburador.",
  "Torque e velocidade suficientes, engrenagens metálicas, rolamentos, faixa térmica e vibração.",
  "PWM do controlador; linkagem com mola de retorno para marcha lenta/corte.",
  "Ciclagem, retorno seguro, vibração e perda de sinal.")
p("Propulsão cruzeiro", "Módulo de corte da ignição", "1", "TBD crítico", "Kill switch optoisolado",
  "Desligar o motor por comando ou failsafe.",
  "Isolação elétrica, estado seguro sem sinal, compatível com tensão/corrente da ignição.",
  "Pixhawk/relé de segurança e módulo de ignição.",
  "Corte por RC, autonomia, geofence, perda de alimentação e EMI.")
p("Propulsão cruzeiro", "Sensor de RPM do motor térmico", "1", "TBD", "Sensor Hall/óptico isolado",
  "Confirmar rotação, partida e falhas do motor.",
  "Faixa ≥12.000 rpm, imunidade EMI e saída compatível com autopiloto/computador.",
  "Eixo/ímã ou ignição; entrada isolada.",
  "Comparação com tacômetro e teste com ignição ativa.")
p("Propulsão cruzeiro", "Motor elétrico starter-generator", "1", "TBD crítico", "BLDC dimensionado para partida e geração",
  "Dar partida no motor a gasolina e gerar energia em cruzeiro.",
  "Torque de partida, rotação, potência contínua de geração, refrigeração e massa definidos por ensaio.",
  "Acoplamento unidirecional, controlador bidirecional e barramento elétrico.",
  "Partida a frio/quente, geração contínua, overspeed e falha desacoplada.",
  "Torque de partida do DLE35RA e balanço de energia.")
p("Propulsão cruzeiro", "Controlador bidirecional starter-generator", "1", "TBD crítico", "Inversor/retificador BLDC bidirecional",
  "Controlar partida e regular carga do barramento/bateria.",
  "Tensão 12S, corrente de partida, regeneração controlada, proteção contra sobretensão.",
  "Starter-generator, barramento, BMS/monitor e controlador.",
  "Transições motor/gerador, carga rejeitada, sobretensão e perda de comunicação.",
  "Motor starter-generator e arquitetura de bateria.")
p("Propulsão cruzeiro", "Embreagem/roda livre e transmissão", "1 kit", "TBD crítico", "Roda livre + correia/engrenagem",
  "Acoplar partida/geração sem impor risco mecânico ao motor térmico.",
  "Torque, rotação, vida e contenção dimensionados; guarda física contra fragmentos.",
  "Virabrequim/eixo e starter-generator.",
  "Torque limite, overspeed, desalinhamento, perda de lubrificação e contenção.",
  "Layout mecânico e análise torsional.")
p("Combustível", "Tanque ou bladder de combustível", "1", "TBD crítico", "Capacidade geométrica inicial 4 L",
  "Armazenar gasolina/óleo para a missão.",
  "Compatível com gasolina, respiro seguro, anti-vazamento, sump; capacidade final pelo ensaio de consumo + reserva.",
  "Linhas, filtro, clunk, respiro e sensor de nível.",
  "Estanqueidade, vibração, expansão térmica, alimentação em atitudes e crashworthiness básica.",
  "Consumo medido e requisito de 400 km.")
p("Combustível", "Kit de linhas, filtro, clunk e respiro", "1 kit", "TBD", "Componentes compatíveis com gasolina",
  "Conduzir e filtrar combustível em todas as atitudes.",
  "Tubos resistentes a gasolina, filtro inspecionável, clunk e respiro anti-sifão.",
  "Tanque e carburador.",
  "Vazão, bolhas, vazamento, atitude e vibração.")
p("Combustível", "Válvula de corte de combustível", "1", "TBD crítico", "Válvula fail-safe compatível com gasolina",
  "Isolar o combustível em emergência/manutenção.",
  "Baixa perda de carga, compatibilidade química, posição segura definida.",
  "Linha entre tanque e carburador; comando de segurança.",
  "Vazamento, vazão, falha de energia e acionamento remoto.")
p("Combustível", "Sensor de nível/fluxo de combustível", "1", "TBD", "Sensor compatível com gasolina",
  "Estimar combustível restante e consumo real.",
  "Baixa restrição, precisão calibrável e compatibilidade química.",
  "Linha/tanque; entrada do computador/autopiloto.",
  "Calibração volumétrica, vazão pulsante e temperatura.")
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

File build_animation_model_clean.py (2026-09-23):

"""Headless builder that applies FreeCAD container-scope corrections in memory."""

from pathlib import Path

source_path = Path(__file__).resolve().parent / "uav_cargo_animation" / "build_animation_model.py"
source = source_path.read_text(encoding="utf-8")
source = source.replace('"App::PropertyLink", "ParentBody"', '"App::PropertyLinkGlobal", "ParentBody"')
source = source.replace('"App::PropertyLink", "MovingPart"', '"App::PropertyLinkGlobal", "MovingPart"')
source = source.replace('"App::PropertyLink", "MovingBody"', '"App::PropertyLinkGlobal", "MovingBody"')
source = source.replace(
    'markers = doc.addObject("App::DocumentObjectGroup", "RotationMarkers")',
    'markers = doc.addObject("App::FeaturePython", "RotationMarkers")',
)
source = source.replace("    markers.addObject(marker)\n", "")
source = source.replace("markers.addObject(cg_marker)\n", "")
namespace = {"__file__": str(source_path), "__name__": "__main__"}
exec(compile(source, str(source_path), "exec"), namespace)

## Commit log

2026-09-23 Sync local project files
    [BOM_Compras.csv, CargoUAV_CFD.FCStd, CargoUAV_HybridVTOL_Animated.FCStd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]
2026-09-24 Novos estudos de malha
    [CargoUAV_cruise_m.stl, CargoUAV_cruise_m_original.stl, CargoUAV_cruise_mm.step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]
2026-09-27 novas modelagens.
    [Aircraft rigid-body assembly (Meshed).stl, CargoUAV_HybridVTOL_Manufacturable.FCStd, CargoUAV_manufacturable_m.stl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]
2026-09-27 vault backup: 2026-09-27 17:42:14
    [CargoUAV_airframe_fixed.step, CargoUAV_fuselage_v2.FCStd, CargoUAV_fuselage_v2.step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]
